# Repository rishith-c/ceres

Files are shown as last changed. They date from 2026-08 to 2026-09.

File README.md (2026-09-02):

# CERES — Field Triage Rover

**A rover that tells you *why* a plant is suffering — thirst, disease, or pests — by
probing the soil, studying the leaves, and fusing both into one honest verdict per plant.**







## Awards

**🏆 2nd Place, Berkeley Robotics Hackathon 2026** (UC Berkeley eHub, August 31) —
won by the only high-school team at a predominantly UC Berkeley student event.

Built by **Rishith Chennupati & Varun Chilukuri**.
Deep technical companion: **[ARCHITECTURE.md](ARCHITECTURE.md)** · agent index: **[llms.txt](llms.txt)**

Every plant monitor gives you numbers. Ceres gives you a diagnosis — and when it isn't
sure, it says **"needs a human"** instead of guessing. Abstention is a feature.

---
 
## How it thinks

```mermaid
graph LR
  A[soil probe<br/>capacitive · 2-pt calibrated] --> C
  B[camera · 4 fenced poses] --> V[VLM leaf classifier<br/>disease vs pest · confidence-gated]
  V --> M[2-of-4 frame vote<br/>abstain by default] --> C[9-rule fusion table<br/>moisture × leaf]
  C --> R[one cause-tagged verdict<br/>fine · dry · sick · needs human]
```

And one full plant stop, as the machines see it:

```mermaid
sequenceDiagram
  participant Pi
  participant Mega
  participant Servo as Probe/Tilt
  Pi->>Mega: PROBE 100
  Mega->>Servo: slewed, pulse-fenced descent
  Note over Mega: FWD refused while probe deployed
  Pi->>Mega: STATUS (settled?) — doubles as watchdog keepalive
  Pi->>Pi: read moisture · dwell · retract
  Pi->>Mega: TILT poses ×4 → capture ×4
  Pi->>Pi: classify ×4 → vote → fuse
  Pi-->>Pi: verdict → live plant board
```

The fusion table is explicit and total — a judge asking "what happens at moisture 0.42
and leaf confidence 0.55?" gets a table lookup, not a vibe. Run `python3 pi/triage.py`
to print it.

## The machine

| Layer | Hardware | Job |
|---|---|---|
| Reflexes | Arduino Mega 2560 | serial protocol, timed motion, 400 ms host watchdog, per-joint safety fences |
| Drivetrain | 2× L298N, 4× TT motors | skid-steer: fwd/rev/spin/arc (12-pin independent wiring) |
| Actuators | PCA9685 → MG90S probe (rack & pinion), MG996R tilt | fenced travel measured on the real hardware |
| Brain | Raspberry Pi 4 (USB-boot) | camera, web GUI + dashboards (systemd), vision pipeline, serial master |
| Heavy vision | laptop over WiFi | YOLOv5n plant tracking (~127 ms/frame), closes a visual-servo loop on the turret |

Web surfaces served by the rover's own Pi (no cloud required):
`:8081` Rover Remote — phone teleoperation, live MJPEG feed, hold-to-drive, one-button
kinematic show · `:8080` live plant board · `:8080/farm` the Farm Board display.

## Safety, by construction

- No untimed motion; every drive command auto-stops; host silence >400 ms cuts motors
- Probe and tilt clamped **at the pulse-write level** to travel limits measured on the
  physical mechanism (the tilt limit was found by successive approximation after it
  hammered its stop — the number is earned, not assumed)
- Driving is refused while the probe is deployed, and vice versa
- 46 automated tests, all passing on the Pi itself: `cd pi && pytest tests`

## Honest ledger

Things that broke and what we did (full narrative in [STATUS.md](STATUS.md)):
- The original L298P motor shield died to reversed battery polarity → dual-L298N architecture
- One MG996R's control board fried (self-drives on bare power) → **retired; the wheels
  became the pan axis** — short spin bursts aim the whole rover
- Rear motors were wired mirror-image → fixed in the firmware direction table
- Campus-network USB noise corrupted serial during streaming → choreography moved on-board
- Not yet done: leaf vision against the live API (needs a key), soil sensor soldering,
  drivetrain on real soil, probe rack limit calibration

## Provenance

This repo's git history **is** the build card: everything before the hackathon's kickoff
commit existed before the event, and everything after was built during it. The probe
module CAD from the original design was lost and is documented as such — nothing here
claims to be more finished than it is.

## Repo map

`firmware/` Mega sketches (rover_motion is the real one; the rest are bench tools) ·
`pi/` the brain: driver, fusion, calibration, vision, GUI, dashboards, 46 tests ·
`mac_tools/` neural leaf tracking · `cad/` surviving chassis CAD + mock assembly ·
`HANDOFF.md` the original design document · `STATUS.md` the living build log

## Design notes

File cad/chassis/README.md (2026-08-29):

# Field Triage Rover — Chassis, Mounts and Turret, v1

Ten parts. Same standard as the probe module: every dimension traced to a
source, boolean-checked, rendered from six angles and inspected before release.

## Chassis geometry

| | |
|---|---|
| Deck | 200 × 140 × 5 mm, top face at Z = 45 mm |
| Wheelbase | 124 mm |
| Track | 170 mm |
| **Overall width with wheels** | **196 mm** |
| Axle height | 32.5 mm (65 mm wheels) |
| Under-deck clearance | 33 mm to the rib bottoms |
| Uno + shield stack top | Z = 87 mm |

**196 mm is the number to check against your row spacing.** You never gave me
pot spacing, so this is sized for a comfortable printed plate, not for your
demo bed. If your pots are closer than ~250 mm on centre, tell me and I'll
narrow the track — it costs one parameter.

The deck top at Z = 45 is not arbitrary: it's set by the 65 mm wheel radius plus
the TT gearbox height, and it's the same Z the probe frame's flange was designed
to bolt to. The two modules line up without adjustment.

## Parts

| File | Qty | Print orientation |
|---|---|---|
| `01_deck` | 1 | flat, ribs up (they print as walls, no support) |
| `02_motor_clamp` | **4** | mouth up |
| `03_motor_gauge` | 1 | flat — **print this first** |
| `04_pi_tray` | 1 | flat |
| `05_uno_tray` | 1 | flat |
| `06_powerbank_sling` | 1 | flat |
| `07_lipo_cradle` | 1 | flat |
| `08_turret_base` | 1 | open face up |
| `09_turret_yoke` | 1 | base down |
| `10_cam_cradle` | 1 | cradle face down |

PETG, 0.2 mm, 4 perimeters, 40% gyroid. Nothing needs support material.

## Three decisions that were made deliberately

**The motor clamp ignores the TT motor's own screw holes.** Vendors disagree on
that pattern and I have not measured yours, so the clamp grips the gearbox body
instead and pulls closed with two M3 bolts into captive hex nuts. It cannot be
wrong about a hole pattern it never uses. Print `03_motor_gauge` first — if the
gearbox does not slide in under light thumb pressure, measure it and tell me
before you print four clamps.

**The LiPo cradle is a strap tray, not a pocket.** You have never given me the
gel-blaster pack's case dimensions, and 3S 2000 mAh bricks range from about
95 × 30 × 20 to 115 × 40 × 28. A toleranced pocket would be a guess dressed up
as precision. The tray takes anything in that range and holds it with two velcro
straps.

**The camera mounts through the C920's 1/4"-20 tripod socket.** That thread is
the one dimensionally guaranteed feature on the camera; the clip's moulded shape
differs between revisions. A raised anti-rotation pad stops the camera pivoting
about the single screw.

**The turret uprights sit outboard at X = ±40.** The C920 is roughly 94 mm wide,
so an inboard yoke would have to be narrower than the camera it carries. Putting
them outboard also lets the tilt servo mount with its long axis horizontal, so
its 53.6 mm tab span fits a 60 mm upright instead of forcing a 66 mm post.

**The pan servo does not carry the camera's overturning moment.** The yoke has a
printed thrust collar that rides in a bore in the turret base. The servo spline
sees torque only. Without this, an MG996R's output bearing takes a bending load
it was never specified for, and the turret develops a wobble by the second hour.

## Assembly order

1. Motor gauge → verify → print four clamps.
2. Clamps to the deck underside, motors in, clamp bolts snug **but not crushed** —
   the gearbox is moulded plastic and will deform.
3. Wheels on. Roll it on the demo surface before adding anything else. If a
   65 mm plastic wheel won't get traction on your soil bed, everything above
   this line is wasted.
4. Power bank sling and LiPo cradle underneath, straps through the deck slots.
5. Pi tray and Uno tray on top. **Nothing may be mounted within 34 mm above the
   Uno tray** — the Inland shield stacks 30 mm and needs finger room above that.
6. Probe frame bolts to the front-edge flange holes; its throat drops through
   the slot in the deck's front edge.
7. Turret base at the rear, yoke on the pan horn, cradle between the uprights.

## Still open

- **Row / pot spacing.** Drives the 196 mm overall width.
- **Motor wiring:** four motors paired onto shield channels A and B, or servos
  moved to a PCA9685 on the Pi so all four channels stay free. This does not
  change any printed part, but it changes what goes on the deck.
- **Wheel choice.** Modelled at the standard 65 × 26 mm TT wheel. A different
  diameter moves the deck height and breaks alignment with the probe frame.

## QC performed

All ten parts watertight, winding-consistent, single-solid, and inside the
Neptune 4 envelope printed flat. Two defects were caught by rendering and fixed:
the turret yoke was two disconnected lumps because the tilt servo pocket cut
clean through the upright, and the original yoke geometry was narrower than the
camera it was supposed to hold.

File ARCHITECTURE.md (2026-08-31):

# Ceres — Architecture & Engineering Notes

The deep-dive companion to the README. Everything here is implemented and testable in
this repo unless explicitly marked as inherited design analysis.

## 1. System topology

```mermaid
graph LR
  subgraph Laptop["Laptop (heavy vision)"]
    T[YOLOv5n tracker<br/>~127 ms/frame CPU]
  end
  subgraph Pi["Raspberry Pi 4 (brain)"]
    G[drive_gui.py :8081<br/>teleop + MJPEG + show]
    D[dashboard.py :8080<br/>plant board + /farm]
    S[station.py<br/>scan → vote → fuse]
    L[leaf.py → Claude VLM]
  end
  subgraph Mega["ATmega2560 (reflexes)"]
    P[serial protocol<br/>115200 8N1]
    W[400 ms watchdog]
    F[pulse-level fences]
  end
  T -- "HTTP /stream, /cmd" --> G
  G -- "USB serial" --> P
  S --> L
  P --> M1[2× L298N → 4× TT motors]
  P --> M2[PCA9685 → probe MG90S ch1, tilt MG996R ch3]
```

## 2. Serial protocol and its timing model

ASCII, newline-terminated, request→`OK|ERR` reply. Commands: `PING FWD REV SPIN ARC
RARC STOP PROBE PAN TILT PANSPIN HOME STATUS`.

The safety-critical property is the interplay of three timers:

| Timer | Value | Consequence |
|---|---|---|
| motion burst | per-command `ms` ≤ 10 000 | no untimed motion exists |
| host watchdog | 400 ms since last RX byte | silent host ⇒ motors cut mid-burst |
| teleop repeat | client streams a 600 ms burst every 300 ms | continuous drive while held |

Result: releasing a button, losing WiFi, or a crashed client all converge to a stop in
≤ 600 ms without any cleanup code running anywhere. The GUI's status poll doubles as the
keepalive during long moves — liveness and telemetry are the same packet.

## 3. Joint fences: measured, then enforced at the lowest level

All servo writes funnel through one function that clamps in pulse space (µs), below the
command layer — so no code path, present or future, can exceed a limit:

- **Tilt 74°–118°.** The floor was found by successive approximation after the mechanism
  hammered its end-stop: lower the bound, listen, repeat. The passing value is the fence.
- **Probe window (pulse-domain, inverted map).** The rack runs mirrored to the original
  design assumption, so `PROBE 0 (retracted) = high pulse`, `PROBE 100 = low pulse`. The
  retracted-detection predicate and the drive interlock were re-derived for the inverted
  map — driving is refused unless the probe is *physically* up, not nominally up.
- **Per-channel slew limits** (µs/s) shape every motion; unused PCA9685 channels are
  actively silenced (zero pulse width) so a floating or failed servo cannot be driven.

## 4. Drivetrain control

Two L298N bridges, all 12 control pins independent, one motor per 2 A channel. Direction
polarity per motor lives in a firmware table (`FWD_HIGH[4]`) — the rear pair is inverted
there because bench testing showed mirror-image wiring; fixing it in the table beats
re-soldering under deadline. Arcs run the inner side at 40 % duty for car-like veers.
PWM is capped at 160/255: 3–6 V motors on an ~9 V post-bridge rail; 160/255 · 9 V ≈ 5.6 V
average at the motor.

After one MG996R's control board failed (it self-drives with no signal — retired), the
pan axis was re-architected onto the drivetrain: short differential spin bursts aim the
whole rover. The tracker compensates with a longer settle cooldown (§6).

## 5. Sensing → judgment

**Moisture** (Adafruit 4026, capacitive, I²C 0x36): raw counts two-point calibrated
(dry air = 0, submerged = 1) with plausibility bounds; a boot self-check makes a broken
probe read as FAULT, never as drought.

**Leaves**: 4 fenced camera poses per plant; each frame classified by a constrained-JSON
VLM call (verdict ∈ {healthy, anomalous, abstain}, cause ∈ {disease, pest}, confidence).
Voting: conviction requires ≥ 2 frames confidently anomalous; acquittal requires ≥ 2
confidently healthy and zero confident convictions; anything else abstains.

**Fusion** is a total function over {LOW, NORMAL, FAULT} × {HEALTHY, ANOMALOUS, UNKNOWN}
— nine explicit rules, thresholds MOISTURE_LOW = 0.35 and confidence floor 0.70. Design
property: no path converts uncertainty into an accusation; every uncertain cell lands on
UNDERWATERED-with-caveat or NEEDS_HUMAN. `python3 pi/triage.py` prints the table.

## 6. Visual servoing (laptop)

YOLOv5n (COCO class 58 "potted plant") through OpenCV DNN, letterboxed 640², ~127 ms/frame
CPU; falls back to HSV green-region segmentation for handheld leaves. Control: deadbands
0.10 (tilt) / 0.18 (pan) of frame; tilt corrects 2° per 320 ms; horizontal correction is a
250 ms spin burst with a 2.2 s cooldown (chassis motion shakes the camera — the loop waits
out its own disturbance). Pan polarity is **self-learning**: after each correction the
tracker checks whether horizontal error shrank; two consecutive regressions flip the
direction mapping at runtime.

## 7. Probe mechanism — inherited design analysis

The original probe drivetrain analysis (design documents; the CAD itself was lost before
this build): module 2, z = 18 pinion, Ø36 mm pitch circle — 0.314 mm of rack travel per
servo degree; MG996R stall derated to the 5.5 V rail gives 56.3 N of linear force against
a 21.9 N moist-soil insertion load (SF 2.57); Lewis tooth stress 7.59 MPa (SF 2.37 in
PETG); guided-blade buckling SF > 100. The current build substitutes an MG90S (~12 N at
stall through the same pinion) at the builder's direction — sufficient only for loose
potting mix, and recorded as such rather than re-rated.

## 8. Power tree

```
3S LiPo (11.1 V, 30C) ─┬─► L298N #1 ─► L298N #2      (motor rail, daisy-chained)
                       └─► buck → 6.0 V ─► PCA9685 V+ (servo rail, own return path)
power bank ─► Pi (USB-C) ─► Mega (USB data+power)
single common ground; servo current returns via the PCA9685 terminal block,
never through the Mega/USB ground (learned the hard way — see failure ledger)
```

## 9. Failure ledger with root causes

| Failure | Root cause | Response |
|---|---|---|
| L298P shield dead | reversed battery polarity at BAT terminals | dual-L298N architecture; polarity ritual |
| Serial corruption / USB dropouts | servo return current through USB ground + cable | ground re-route; on-board choreography; link-quality PING metric (n/60) |
| Wheels fought on every command | rear motors wired mirror-image | firmware polarity table |
| Tilt hammering | commanded past unmeasured mechanical floor | successive-approximation calibration → fence |
| Servo self-drives unpowered inputs | fried control board (confirmed: spins with zero pulses) | retired; wheels became pan axis |
| Twitch at power-on | MCU boot window leaves EN pins floating | battery-last power order; pull-down fix documented |

## 10. Verification

46 tests, all runnable on the target Pi (`cd pi && pytest tests`): protocol framing and
error taxonomy, watchdog-keepalive behavior, every fusion cell and both thresholds at
their boundaries, calibration bounds and fault paths, vision abstention on seven failure
modes, scan-pose fencing and vote outcomes. Firmware compiles warning-clean for
`arduino:avr:mega`; every flash in the log was verified by avrdude readback.

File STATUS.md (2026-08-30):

# Project status — the rover is named CERES

## 2026-08-30 late — PI↔MEGA INTEGRATION LIVE
Mega on the Pi's USB (/dev/ttyACM0). Rover Remote GUI (pi/drive_gui.py)
runs as systemd service on :8081 — live MJPEG camera feed, hold-to-drive
pad (600 ms bursts, watchdog-safe), tilt/pan/probe controls, live status.
First Pi-commanded motion executed via the full chain (browser→Pi→serial→
firmware). Dashboard on :8080. Both survive reboot.

## 2026-08-30 evening — Pi COMMISSIONED
Pi 4 ("varun", user varun, 10.59.112.136 on campus net + RPi Connect as
backup) boots from 128 GB USB (102 GB free), reachable by key-auth SSH
from the Mac. Code deployed to ~/rover with venv (.venv, system-site,
cv2 4.10 via apt + anthropic/pyserial/pytest via pip). **All 45 tests
pass ON THE PI.** Remaining to first real leaf judgment: export
ANTHROPIC_API_KEY on the Pi, plug Mega + C920 into Pi USB.

## 2026-08-30 — vision + scan pipeline ready for the Pi
`pi/` now carries the whole per-plant inspection chain, hardware-free
tested (45 tests): `camera.py` (C920 capture, warmup burst),
`leaf.py` (Claude vision; verdict + **cause: disease vs pest** + abstain),
`station.py` (`scan_plant()`: 4 fenced poses, staggered pan nudges,
majority-with-abstention across frames, fused into a flag; moisture=None
honestly abstains until the soil sensor is wired). Pi setup needs:
`pip install pyserial anthropic opencv-python` + `ANTHROPIC_API_KEY`.
Pi boots from USB (SD dead); SSH was not enabled in the image — fix by
dropping `ssh` + `userconf.txt` on the boot partition. No plant-training
data exists on the WC18 drive (industrial video only) — the VLM route is
deliberate, per HANDOFF known-problems.

## MILESTONE 2026-08-29 late: full bench bring-up complete
Every actuator verified moving under serial command on the Mega:
wheels (timed + watchdog), probe (gentle, fenced), tilt (positional),
pan (PANSPIN timed nudges — the servo is a continuous type). Link clean.
Tilt mechanism calibrated 2026-08-30: hammers its stop below ~74 deg;
firmware now fences TILT to 74-118 (like the probe's 30-150 fence).
firmware/turret_duet is a standalone USB-free pan/tilt show (74-118 wave,
staggered pan nudges — simultaneous big-servo peaks caused intermittent
hammering; USB streaming reliably kills the link until the ground/cable
fix happens). Still open before the hackathon: probe rack limit calibration, drivetrain
on real ground, deck reprint (axis defect), probe CAD recovery/rebuild,
a real positional pan servo, 5 A servo buck + inline fuse for demo day.

# Project status — 2026-08-28 session

## What happened to the files

Only the chassis half of the project survived on this machine, in
`~/Developer/files/` (copied here under `cad/`; the originals were left in
place — treat this repo as canonical from now on and delete `~/Developer/files`
when convenient). Searched the whole disk, Downloads archives, and git
history: **these HANDOFF §6 files are lost**, not misplaced:

- `firmware/rover_motion.ino` (original) — **rebuilt this session**, see below
- `cad/probe_module.py` + probe STEP/STL/renders — **still missing**
- `cad/design_calcs.py` / `design_calcs.txt` — **still missing**
- QC harnesses `build_and_inspect.py`, `build_chassis.py` — **still missing**

The probe module was NOT recreated on purpose: HANDOFF §5 records its locked
design values but not the full part geometry, and §9 forbids replacing
verified numbers with plausible ones. If the original session's outputs exist
anywhere (another machine, a download link, chat history), recover them.
Otherwise the probe CAD must be re-derived properly — through the
aero-mechatronics/cad pipeline, reproducing the §5 numbers exactly — before
printing probe parts. The chassis is fine: its source (`cad/chassis_module.py`)
survived.

## Rebuilt this session

**`firmware/rover_motion/rover_motion.ino`** — rewritten from the HANDOFF §4
spec. Compiles clean for `arduino:avr:uno` (7836 B flash / 492 B RAM). All
specified behaviours implemented: timed motion with auto-stop, 400 ms host
watchdog, PROBE refused while moving, ~83 °/s servo slew, READY banner,
STATUS fields, DIR=digitalWrite / PWM=analogWrite / stop=analogWrite(0).
Deltas from the (unseen) original — flagged, not silent:

- Wiring assumption: **§3 resolution 1** (wheels paired on channels A/B,
  servos on D11/D12/D2). If you pick the PCA9685 route instead, PROBE/PAN/
  TILT/HOME move to the Pi and the firmware shrinks to wheels-only.
- Added the reciprocal safety guard: drive commands are refused while the
  probe is deployed (`ERR probe_deployed`).
- PWM capped at 200/255 in firmware (paired motors ~2.4 A stall vs the 2 A
  L298 channel).
- Baud 115200. Drive durations capped at 10 s.
- The watchdog means the Pi **must keep talking during motion** — the driver's
  `wait_for_stop()` polls STATUS and is that keepalive. Not flashed to
  hardware yet; bench-test PWM polarity (A_FORWARD/B_FORWARD constants) first.

## New this session (HANDOFF §8 tasks 1–4) — 37 tests pass, no hardware needed

- `pi/rover.py` — serial driver: READY sync on connect (reset-on-open),
  OK/ERR/timeout parsing, STATUS dataclass, wait_for_stop/wait_for_settled,
  client-side validation. No sequencing logic, per the task spec.
- `pi/triage.py` — the never-cut fusion layer. Total 3×3 rule table
  (moisture LOW/NORMAL/FAULT × leaf HEALTHY/ANOMALOUS/UNKNOWN), abstention
  first-class. Thresholds: moisture LOW < 0.35, leaf confident ≥ 0.70.
  `python3 pi/triage.py` prints the judge-ready table. The §8 judge case
  (moisture 0.42, confidence 0.55 → NORMAL × UNKNOWN → needs_human) is a
  tested lookup.
- `pi/soil.py` — two-point calibration (raw 200–2000 counts → 0–1) with
  plausibility bounds and a boot self-check, so a broken probe reads as a
  FAULT (→ triage abstains), never as a drought.
- `pi/leaf.py` — hosted-VLM leaf call (Claude, `claude-opus-5`, constrained
  JSON schema). Every failure — no key, no network, refusal, garbage output,
  leaf not visible — returns abstain. Needs `ANTHROPIC_API_KEY` and
  `pip install anthropic` on the Pi. Untested against the live API; the
  parsing/abstention paths are unit-tested with a fake client.
- Run everything: `pytest pi/tests` (needs pytest; pyserial only on the Pi).

## Defect found 2026-08-28 while building the mock assembly (cad/mock_assembly.py)

**The deck's feature axes conflict with the designed track.** The deck is
200 × 140 with the probe notch centered on a 200 mm edge and the turret on the
opposite 200 mm edge — i.e. the features treat the 140 axis as fore-aft. But
the motor clamps at (±56, ±62) put the wheels at X ≈ ±85 (track 170 as
designed), and a Ø65 wheel (top at Z = 65) at X 72–98 passes straight through
the deck plate corners (deck sits at Z ≈ 40–50, spanning X ±100). Track 170 /
overall width 196 is only possible if the deck is ~140 wide at the wheel
stations — the 200 axis must run fore-aft, which contradicts the probe/turret
edge placement. Corroborating signs of the same axis mix-up in `make_deck()`:
half of each motor-clamp bolt pair lands at y = ±74, off the ±70 plate edge;
and `TRACK` is derived from `DECK_W` while the clamp X positions also use
`DECK_W`. Separate 4–5 mm issue: gearbox top sits at Z = 44, so the deck
bottom must be at 45 (per the code's own `DECK_Z` formula) — the README's
"top face at Z = 45" would put the deck bottom at 40, inside the gearboxes.

**Do not print `01_deck` until this is resolved.** Fix in chassis_module.py:
keep the 200 axis fore-aft, move the probe slot/flange to one 140 edge and
the turret pattern to the other, put the wheelbase (±62) along the long axis,
then re-run QC and re-render. The mock viewer shows the clip honestly —
explode it and look at the wheel corners.

## 2026-08-29 — shield died, architecture pivoted

The Inland L298P shield took the 3S pack reverse-polarity (BAT + to −) and
its motor stage is dead: logic LED lives, no channel moves. Uno, motors,
and pack survived. New electrical architecture, replacing HANDOFF §3's
open decision with a hybrid of both options:

- **Wheels:** TWO L298N modules, one per side, all 12 control pins wired
  independently (per the LastMinuteEngineers diagram, at the builder's
  request), now on an **Arduino Mega 2560** (pin map also works on an Uno).
  Board 1 = LEFT: ENA 9, IN1 8, IN2 7, IN3 5, IN4 4, ENB 3 (verified working
  with the LME demo). Board 2 = RIGHT: ENA 10, IN1 11, IN2 12, IN3 13,
  IN4 2, ENB 6.
  Battery daisy-chain: pack + → board1 +12V → jumper → board2 +12V; pack −
  → board1 GND → jumper → board2 GND; one wire board1 GND → Uno GND.
  Per-motor direction flips live in FWD_HIGH[] in the firmware.
- **Servos:** PCA9685 on the **Mega's** I²C (SDA 20, SCL 21) — moved off
  the Pi 2026-08-29 evening so one MCU owns all deadlines and bench testing
  needs no Pi. Roster AS PLUGGED (re-confirmed after two map flip-flops):
  ch0 tilt = MG996R (healthy), **ch1 probe = MG90S** (fenced 900–2400 µs,
  retract = 30°; against the force calc — loose mix only), ch2 pan =
  **DISABLED**: that servo spins continuously on any pulse incl. center
  (continuous-rotation clone or broken). Positional PAN stays disabled, but
  **PANSPIN <ms> <L|R>** (1250/1750 µs, max 2 s, then pulses cut) gives
  working timed nudges — verified moving both directions on the bench. Probe slew ~50°/s,
  pan/tilt ~83°/s. Probe rack travel limits NOT yet calibrated — limit
  finder exists (firmware/probe_limit_finder) but the session stalled;
  carriage reported to crash at fence ends, so the real travel is
  narrower than 30–150°.
- **Firmware v3** (`rover_motion.ino`, Mega + Adafruit PWM Servo Driver
  lib): full HANDOFF §4 protocol restored — wheels AND PROBE/PAN/TILT/HOME,
  7-field STATUS, both interlocks back in firmware (PROBE refused while
  moving, drive refused while probe deployed), ~83°/s slew via PCA9685,
  MAX_PWM 160. `pi/rover.py` matches (probe/pan/tilt/home/sample());
  `pi/actuators.py` + `servo_test.py` retired (git history has them).
- Bench sketches: `firmware/motor_test/` (old shield, 4-channel),
  `firmware/motor_test_l298n/` (interactive), `firmware/motor_demo_4x/`
  (auto-looping LME-style), `pi/servo_test.py` (PCA9685). All compile for
  Mega and Uno.

## Still open (HANDOFF §7 — answers needed, don't guess)

Pot spacing, wheel diameter, TT gearbox gauge, MG996R gauge, and the
A/B-pairing vs PCA9685 wiring decision. Plus §8 task 5 (row sequencing) —
blocked on the stop-at-plant sensing decision.

**LiPo answered 2026-08-29** (Amazon listing, Tosiicop 2-pack): 3S 11.1 V
2000 mAh **30C** (not 10C as HANDOFF §2 said — 60 A short-circuit capable,
the inline fuse is not optional), 106 × 18 × 20 mm, 73 g, SM-2P discharge
plug + XH-4P balance, mini-Tamiya adapter included. Fits the strap-tray
cradle easily. All four TT motors are currently wired to shield channels
A–D for bench testing with firmware/motor_test/motor_test.ino.

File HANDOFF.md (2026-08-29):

# Field Triage Rover — Project Handoff

You are picking up an in-progress hardware project. This document is the single
source of truth. Everything below has been verified against a real source —
datasheets, official CAD files, or vendor spec pages. **Do not silently replace
any number here with a guess.** If a dimension is missing, it is missing on
purpose and is listed under "Open questions" — ask, don't invent.

---

## 1. What this is

A small autonomous rover for the **Berkeley Robotics Hackathon** (two people,
one build day: Rishith Chennupati and Varun Chilukuri).

It drives along a row of potted plants and stops at each one. At every stop it
drives a soil probe into the pot, reads soil moisture and temperature, retracts,
then aims a webcam at the canopy and captures a leaf image. Both signals are
fused **per plant** into one cause-tagged flag — *underwatered* vs *diseased* vs
*fine* — instead of reporting raw numbers a human has to interpret.

**The triage/fusion layer is the differentiator and the last thing to cut.**
A rover that reports four numbers has been built many times; one that says
"plant 14: moisture normal, leaf spotted → likely disease, not water" has not.

Cut order if the schedule slips, worst first:
1. Presentation dashboard — cut first
2. Turret / leaf vision
3. Probe subsystem
4. **Per-plant fusion — never cut**

Judging panel includes people from frontier robotics labs. **Claim only what is
actually built.** A smaller fully-real system beats a larger partly-narrated one.

---

## 2. Hardware inventory — all verified

| Component | Verified dimensions / spec | Source |
|---|---|---|
| Raspberry Pi 4B | 85.0 × 56.0 mm, M2.5 holes on a 58 × 49 rectangle, 3.5 mm inset | RPi mechanical drawing |
| Arduino Uno R3 | 68.6 × 53.4 mm, standard Arduino 4-hole pattern | Arduino |
| Inland L298P 4-ch motor shield | 65 × 50 × 30 mm stacked, 3× M3 fixing holes, PH2.0-2P motor connectors, onboard slide switch, BAT input 7–12 V, <4 A total | Micro Center KB article 678 |
| Adafruit 4026 STEMMA soil sensor | 76.20 × 13.97 × 6.37 mm, 1.57 mm FR4, components occupy 0–19.53 mm from the connector end, **56.67 mm of bare blade** | measured from Adafruit's own STEP file |
| MG996R servo ×3 | 40.7 × 19.7 × 42.9 mm, tab span 53.6, hole pitch 49.5, stall 9.4 kgf·cm @4.8 V / 11.0 @6.0 V, stall current 2.5 A | TowerPro, cross-checked Waveshare + Handson |
| Yellow TT gearmotor ×4 | 70 × 37 × 22.5 mm, dual shaft, 1:48 | vendor spec — **hole pattern NOT verified** |
| TT wheel ×4 | assumed 65 mm dia × 26 mm — **not confirmed** | assumption |
| Logitech C920 webcam | mounts via its 1/4"-20 UNC tripod socket | Logitech |
| Energizer power bank | 148.59 × 68.33 × 17.53 mm, 10,000 mAh, 22.5 W | Micro Center listing |
| 3S LiPo (gel-blaster pack) | 11.1 V 2000 mAh 10C, SM-2P plug — **case dimensions NOT measured** | user |
| Printer | Elegoo Neptune 4, 225 × 225 × 265 mm, 0.4 mm nozzle | — |

### Corrections to bad vendor data — do not regress these

- Micro Center lists the 4026 as **"Temperature, Humidity"** with **"Range 100mm
  to 2000mm."** Both wrong. It is a capacitive soil-moisture sensor; 200–2000 is
  the **raw capacitance count** (dry→wet), not millimetres. Temperature is the
  ATSAMD10's internal die sensor, ±2 °C.
- **There is no humidity sensor in this build.** The project write-up says
  "moisture, temperature, humidity." Only the first two exist. Either add an
  SHT31/DHT22 or drop the humidity claim from the pitch.
- The Inland KB article's example sketch has broken `pinMode` calls (it sets
  `MAPin` four times and never `MBPin`/`MCPin`/`MDPin`). Don't use it as a reference.

---

## 3. Electrical architecture

### Motor shield pinout (verified)

| Channel | Direction pin | PWM pin | AVR timer |
|---|---|---|---|
| A | D3 | D6 | Timer0 |
| B | D4 | D5 | Timer0 |
| C | D7 | D10 | **Timer1** |
| D | D8 | D9 | **Timer1** |

### HARD CONSTRAINT — read this before touching motor code

On an Uno R3 the **Servo library owns Timer1**, which is the timer that generates
PWM on **D9 and D10**. The moment any servo is attached, channels C and D lose
speed control and become on/off only.

There are four TT motors and three servos. They cannot coexist on this shield.

Two acceptable resolutions:
1. **Pair the wheels.** Left two motors into channel A, right two into channel B.
   Skid-steer 4WD cannot use independent per-wheel speed anyway. C and D stay
   empty and the conflict disappears. Cost: ~2.4 A stall through a 2 A channel,
   so cap PWM and never let them stall.
2. **Move all three servos to a PCA9685** on the Pi's I²C bus (~$8). Arduino does
   wheels only; the Pi drives the turret and probe. Cleanest split, and it puts
   the camera and the turret on the same machine. Cost: one extra part.

**This decision is still open.** It does not change any printed part.

### Board choice: Uno R3, not R4

R3 was chosen deliberately. The Servo/Timer1 interaction on AVR is documented
with a known workaround; the equivalent behaviour on the R4's Renesas timers is
not. The R4 also has a core bug where `digitalWrite()` on a pin that previously
saw `analogWrite()` does not restore a clean rail. The firmware respects that
anyway: **DIR pins are only ever `digitalWrite`, PWM pins only ever `analogWrite`,
and motor stop is `analogWrite(pin, 0)`.** Keep it that way.

### Free pins after the shield

Shield occupies D3–D10. Free: **D2, D11, D12, D13, A0–A5.**
Servos go on **D11, D12, D2**. Avoid D13 (onboard LED + resistor) and D0/D1
(hardware UART — also where the shield's HM-10 header sits, and the same UART
the Pi's USB connection uses; leave that header unpopulated).

### Power rails

The pack is a 3S LiPo at 10C — 20 A available. Steady-state draw is ~1.1–1.3 A,
worst case ~3.5 A. Capacity is not the constraint; rail separation is.

| Rail | Feeds | Notes |
|---|---|---|
| 8.5 V buck | Shield **BAT** terminal | Shield spec is 7–12 V; 8.5 V puts ~6 V on the motors after the L298 bridge drop. Raw 11.1 V would put ~8.6 V on 3–6 V motors. |
| 5.5 V buck, **5 A minimum** | 3× servo V+ only | MG996R stalls at 2.5 A each. A 3 A buck is undersized. |
| 5.1 V buck | Raspberry Pi | Pi then powers the Uno over USB. |

Non-negotiables: inline fuse on the pack positive, 3S low-voltage alarm on the
balance lead, common ground star point, 1000 µF at the servo rail and 470 µF at
the shield BAT input. The shield's onboard slide switch **is** the master switch —
don't add a second one. The Uno auto-selects VIN over USB, so having the Pi
plugged in at the same time is safe.

**Never power servos from the Arduino 5 V pin or the shield's regulator.**
That regulator is good for maybe 500 mA against a ~2 A servo peak. This is the
single most common way this exact build dies.

---

## 4. Firmware — already written

`rover_motion.ino` is complete and compiles for the Uno R3. It is a serial slave;
the Pi owns sequencing, vision and triage, the Arduino owns anything with a
deadline.

### Protocol (ASCII, newline-terminated)

```
PING                   -> OK PONG
FWD <ms> <pwm>         -> OK FWD      drive forward, auto-stops after <ms>
REV <ms> <pwm>         -> OK REV
SPIN <ms> <pwm> <L|R>  -> OK SPIN
STOP                   -> OK STOP
PROBE <0-100>          -> OK PROBE    0 = retracted, 100 = fully inserted
PAN <deg> / TILT <deg> -> OK PAN|TILT
HOME                   -> OK HOME
STATUS                 -> OK <drive> <pwm> <probe> <pan> <tilt> <settled> <uptime>
error                  -> ERR <reason>
```

Safety behaviours already implemented, keep them:
- **No untimed motion.** Every drive command carries its own duration.
- **Host watchdog.** If the Pi goes silent while wheels turn, motors cut.
- **`PROBE` is refused while the chassis is moving.** A probe part-way down while
  the rover rolls is a snapped probe.
- **Servos slew at ~83 °/s** rather than snapping.
- A `READY` banner is emitted after init because opening the serial port resets
  the MCU — the Pi should sync on that instead of guessing.

Firmware rules that must hold in any Pi-side driver you write:
- **Never park the probe loaded.** Insert, dwell, retract. Full stall torque is
  fine for a 1–2 s insertion; holding position against soil will cook the servo.
- **Dwell before reading temperature** — the die sensor needs seconds to settle.
- **Two-point calibrate moisture** (dry in air, submerged in water) so the number
  is defensible when a judge asks what the units are.

---

## 5. CAD — already designed and verified

All parametric CadQuery. Two source modules regenerate everything:

- `probe_module.py` — soil probe actuator (5 parts)
- `chassis_module.py` — chassis, mounts, turret (10 parts)
- `design_calcs.py` — every number the probe geometry derives from

### Probe actuator — locked design values

| Quantity | Value | Reasoning |
|---|---|---|
| Insertion depth | 35.0 mm | capped by 56.67 mm bare blade − 20 mm dry margin |
| Throat ground clearance | 12.0 mm | blade tip parks here |
| Stroke | 47.0 mm | clearance + depth |
| Gearing | module 2, z=18 pinion, Ø36 pitch, 12 mm face | smallest set clearing 47 mm at a conservative 150° servo sweep |
| Backlash | 0.30 mm, taken from rack tooth thickness | |
| Linear force at stall | 56.3 N | MG996R derated to the 5.5 V rail |
| Design load | 21.9 N | moist garden soil: tip bearing + skin friction |
| Safety factor | 2.57 (6.43 in loose potting mix) | |
| Gear tooth stress | 7.59 MPa (Lewis) | SF 2.37 in PETG |
| Blade buckling | SF > 100 guided, 3.2 unguided | why the throat exists |
| Dry margin at full insertion | 21.7 mm | |

**Graceful degradation:** the design assumes 150° of servo sweep, which needs a
600–2400 µs pulse range rather than the default 1000–2000 µs. At a worst-case
120° the insertion depth drops to 25.7 mm — shallower but still a valid reading.

**Out of scope:** packed clay needs 52.6 N, above what's reliably available.
Use loose potting mix in the demo pots. That's a variable you control.

### Chassis geometry

| | |
|---|---|
| Deck | 200 × 140 × 5 mm, top face at **Z = 45 mm** |
| Wheelbase | 124 mm |
| Track | 170 mm |
| Overall width with wheels | **196 mm** |
| Axle height | 32.5 mm (65 mm wheels) |
| Uno + shield stack top | Z = 87 mm |

Z = 45 is not arbitrary — it's the 65 mm wheel radius plus the TT gearbox height,
and it's the same Z the probe frame's mounting flange targets. The two modules
bolt together with no adjustment. **If the wheel diameter changes, both modules
must be regenerated.**

### Part list

**Probe module** — `01_frame`, `02_carriage`, `03_pinion`, `04_clamp`, `05_servo_gauge`
**Chassis** — `01_deck`, `02_motor_clamp` (×4), `03_motor_gauge`, `04_pi_tray`,
`05_uno_tray`, `06_powerbank_sling`, `07_lipo_cradle`, `08_turret_base`,
`09_turret_yoke`, `10_cam_cradle`

All 15 parts: watertight, winding-consistent, single-solid, and fit the Neptune 4
envelope printed flat. Boolean interference checks are clear between frame and
carriage at both stroke ends, and between frame and pinion.

### Print settings

PETG, 0.2 mm layers, 4 perimeters, 40% gyroid. No supports on any part.
PLA works but cracks instead of yielding when the probe hits a stone.

**Two orientations are load-bearing, not preferences:**
- `02_carriage` and `03_pinion` must print **flat**, teeth in the layer plane.
  Printed upright the teeth load across layer lines and the Lewis stress
  calculation above is void.
- `01_frame` prints with its −Y face on the bed so all channel walls come out
  vertical and the throat mouth (a loft, not a chamfer) needs no support.

### Design decisions made deliberately — don't "improve" these

- **No printed servo spline anywhere.** A printed 25T spline strips on the first
  stall. The metal horn carries torque; printed parts have a 24 mm horn pocket
  with four radial slots that accept any horn hole between r=5 and r=11, so
  nothing needs drilling.
- **The motor clamp ignores the TT motor's own screw holes.** Vendors disagree
  on that pattern and it hasn't been measured. The clamp grips the gearbox body
  and pulls closed on captive M3 nuts. It can't be wrong about a pattern it
  never uses.
- **The LiPo cradle is a strap tray, not a pocket.** 3S bricks range from about
  95×30×20 to 115×40×28 and this one hasn't been measured.
- **The camera mounts through the C920's 1/4"-20 socket**, with a raised
  anti-rotation pad. That thread is the only dimensionally guaranteed feature;
  the clip's moulded shape varies between revisions.
- **The pan servo carries no overturning moment.** The yoke rides on a printed
  thrust collar in the turret base bore, so the MG996R spline sees torque only.
  Without it the turret develops a wobble within an hour.
- **Turret uprights sit outboard at X = ±40** because the C920 is ~94 mm wide.
- **Two gauge coupons exist for a reason.** `05_servo_gauge` (8 min) and
  `03_motor_gauge` (5 min) verify the two component fits that are based on
  disputed vendor data. Print both before committing to the full parts.

---

## 6. Expected files on disk

```
field-triage-rover/
├── firmware/
│   └── rover_motion.ino
├── cad/
│   ├── design_calcs.py          # regenerates every probe number
│   ├── design_calcs.txt         # last run output
│   ├── probe_module.py
│   ├── chassis_module.py
│   ├── probe_module/{step,stl,render}/
│   └── chassis/{step,stl,render}/
└── HANDOFF.md                   # this file
```

Rebuild everything with CadQuery 2.8 (`pip install cadquery --break-system-packages`).
QC harnesses `build_and_inspect.py` and `build_chassis.py` re-export, re-run the
interference and envelope checks, and re-render six views per part.

---

## 7. Open questions — ask, do not guess

1. **Row / pot spacing.** Drives the 196 mm overall width. If pots are closer
   than ~250 mm on centre, the track has to narrow.
2. **Wheel diameter.** Modelled at 65 mm. Any change moves the deck height and
   breaks probe/chassis alignment.
3. **TT gearbox cross-section.** Print `03_motor_gauge` and confirm before
   printing four clamps.
4. **MG996R tab pattern.** Print `05_servo_gauge` and confirm.
5. **3S LiPo case dimensions.**
6. **Motor wiring:** wheels paired on channels A/B, or servos moved to a PCA9685?

---

## 8. Suggested next tasks, in order

1. **Pi-side Python driver** for the serial protocol in §4 — a `Rover` class with
   connection handling (tolerate the reset-on-open), command/ack parsing, and
   timeouts. No sequencing logic yet.
2. **Fusion rule table.** Four cells: {low, normal moisture} × {leaf healthy,
   anomalous}, each mapping to a flag, plus abstention as a fifth outcome. This
   is testable with no hardware, so it can be built in parallel with mechanical
   debugging. It's also the thing a judge will ask about — "what happens at
   moisture 0.42 and leaf confidence 0.55" needs a table, not an inference.
3. **Moisture calibration routine** — two-point normalisation, plus a boot-time
   self-check so a broken probe reads as a fault rather than as a drought.
4. **Leaf vision call** with confidence-aware abstention ("needs human
   inspection") instead of a forced guess.
5. **Row sequencing** — see the open risk below.

### Known unsolved problems, honestly stated

- **Stopping at the right plant is open-loop.** `FWD 800 120` covers a different
  distance on a table than on soil, and TT motors are badly mismatched
  pair-to-pair. Over six plants the error compounds until the probe hits dirt
  between pots. Cheapest fix: don't measure distance at all — put a reflectance
  sensor or limit switch at each pot and drive until it fires.
- **The leaf model doesn't exist yet.** PlantVillage-trained classifiers report
  ~99% on that dataset and fall apart on real leaves under real lighting.
  Either use a hosted VLM with a constrained prompt, or restrict the claim to
  something classical CV can actually support.
- **The turret has no idea whether the leaf is in frame.** It pans to a fixed
  angle and captures whatever is there.
- **Traction on soil is untested.** TT motors, plastic wheels, a LiPo, a Pi and
  a probe rack is a heavy low-torque platform. Test the drivetrain on the actual
  demo surface before building anything on top of it.

---

## 9. How to work on this

- Don't replace a verified dimension with a plausible-looking one. Every number
  in §2 has a source; if you need one that isn't there, ask.
- Regenerate CAD from the parametric modules — don't hand-edit STLs.
- After any geometry change, re-run the QC harness and **look at the renders**.
  Five real defects in this project were caught by rendering and inspecting from
  six angles, not by the numbers: a throat that trapped the carriage at full
  insertion, a gusset built on the wrong workplane, a pinion placement that drove
  the gear through a side wall, a turret yoke that came out as two disconnected
  lumps, and a yoke narrower than the camera it was meant to hold.
- Prefer a smaller working system over a larger described one. See §1.

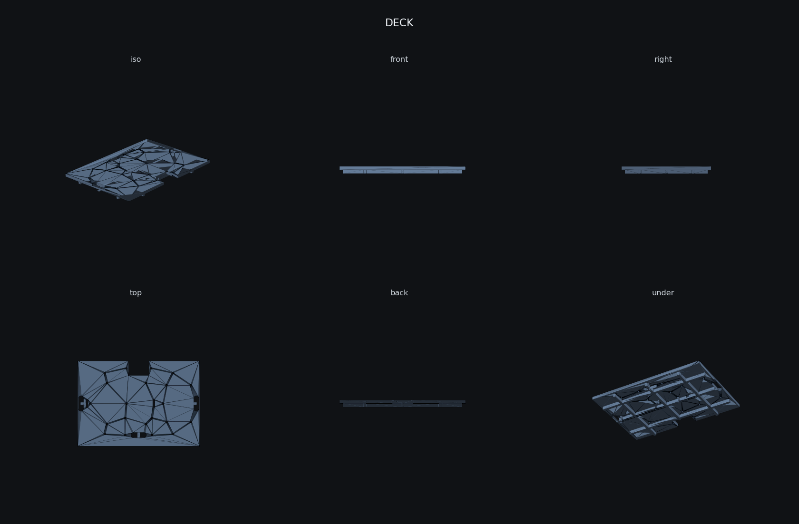
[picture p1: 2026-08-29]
cad/chassis/render/01_deck.png

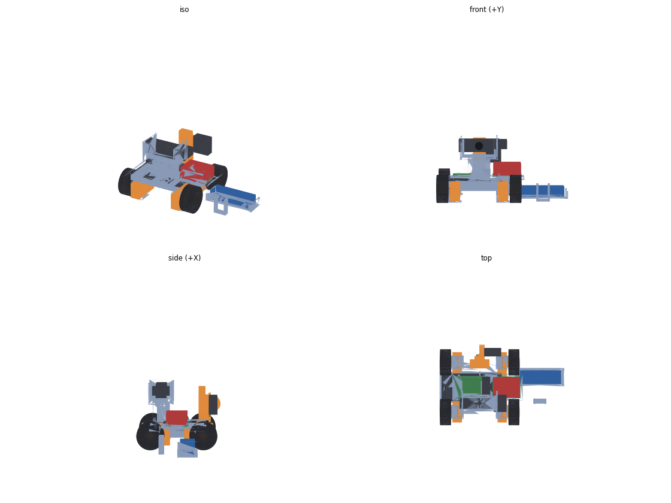
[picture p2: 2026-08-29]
cad/render/mock_qc.png

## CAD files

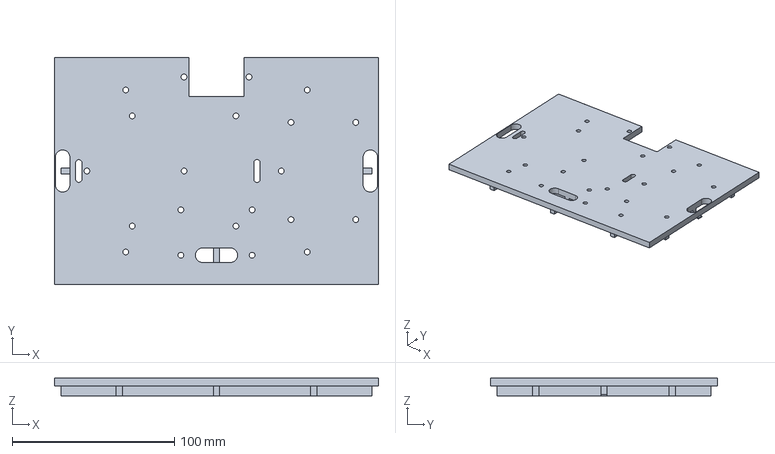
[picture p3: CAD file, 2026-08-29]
cad/chassis/step/01_deck.step
200.0 x 140.0 x 11.0 mm

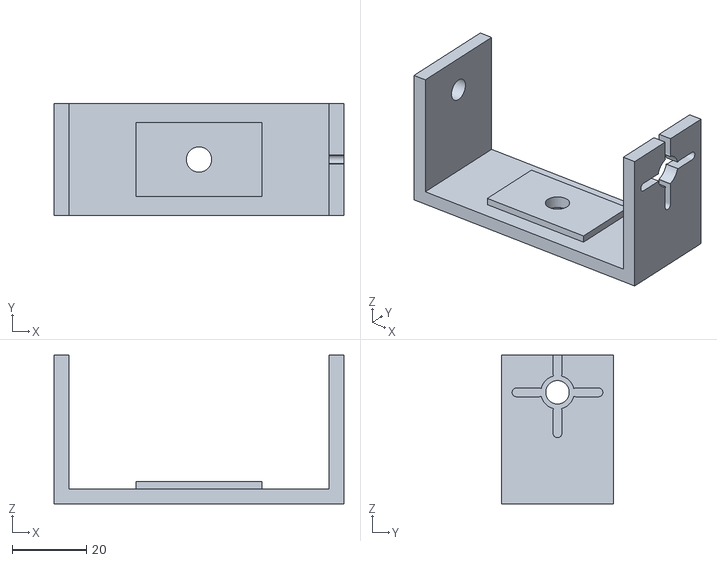
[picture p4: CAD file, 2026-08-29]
cad/chassis/stl/10_cam_cradle.stl
78.0 x 30.0 x 40.0

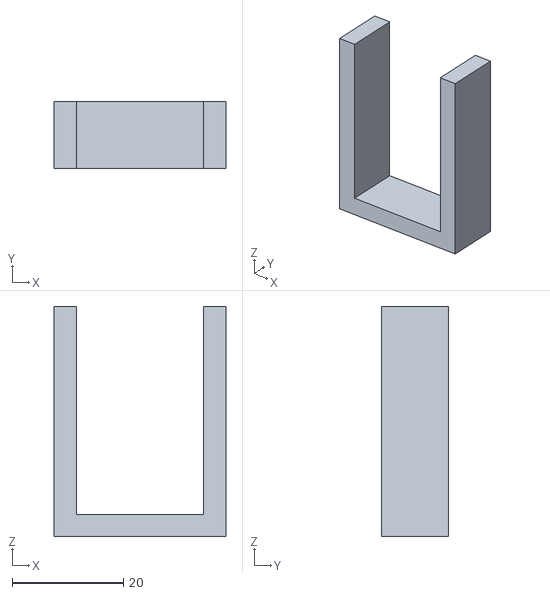
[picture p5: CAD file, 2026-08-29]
cad/chassis/stl/03_motor_gauge.stl
30.9 x 12.0 x 41.3

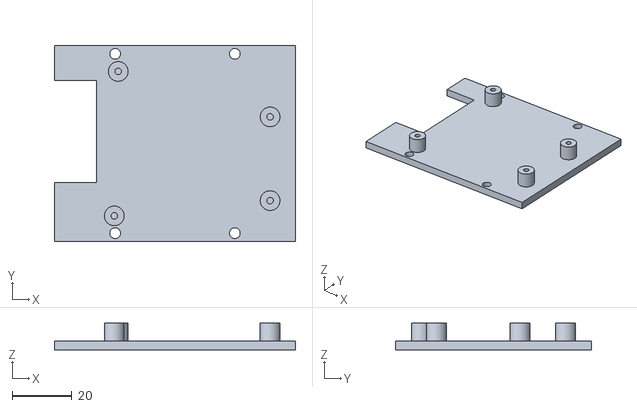
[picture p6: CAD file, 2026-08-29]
cad/chassis/stl/05_uno_tray.stl
80.6 x 65.4 x 9.00

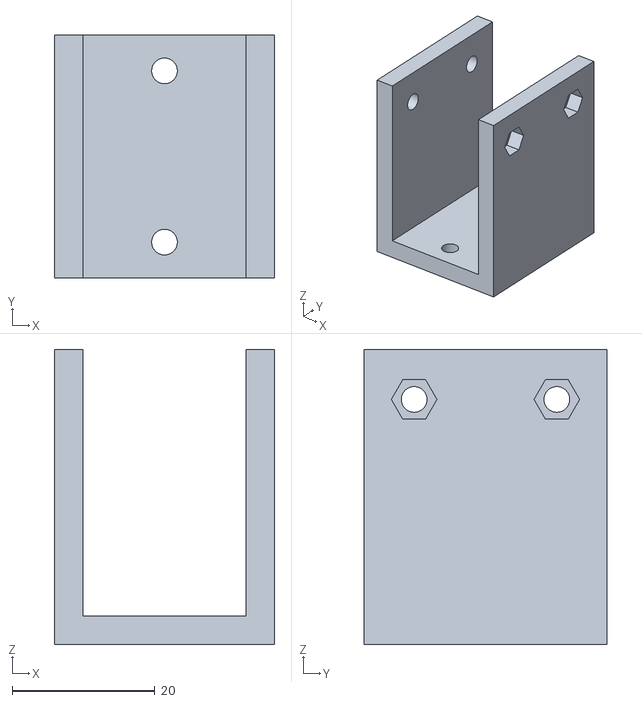
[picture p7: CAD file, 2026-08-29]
cad/chassis/stl/02_motor_clamp.stl
30.9 x 34.0 x 41.3

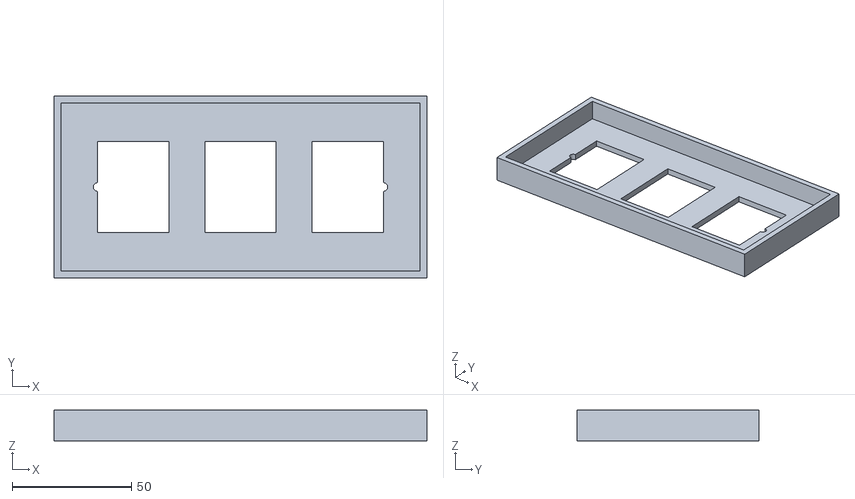
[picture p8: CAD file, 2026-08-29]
cad/chassis/stl/06_powerbank_sling.stl
156.6 x 76.3 x 13.0

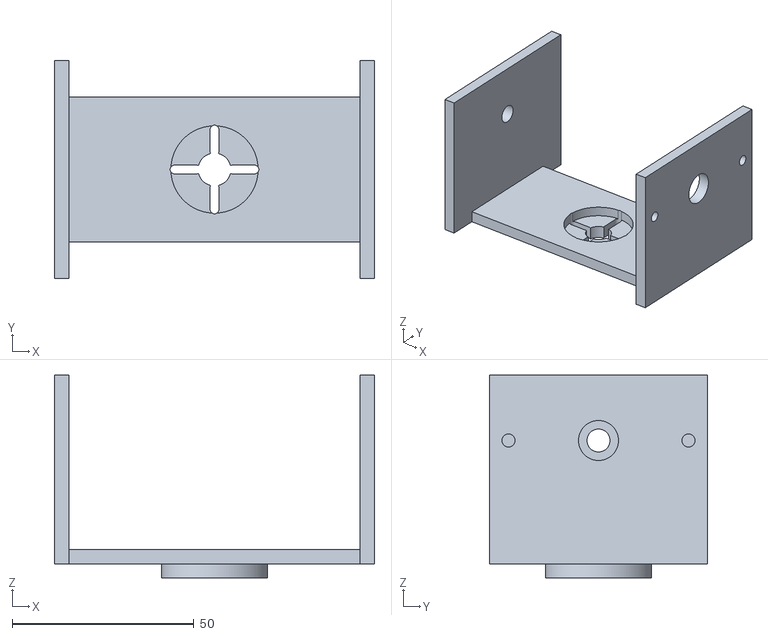
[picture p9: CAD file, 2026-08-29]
cad/chassis/stl/09_turret_yoke.stl
88.0 x 60.0 x 55.8

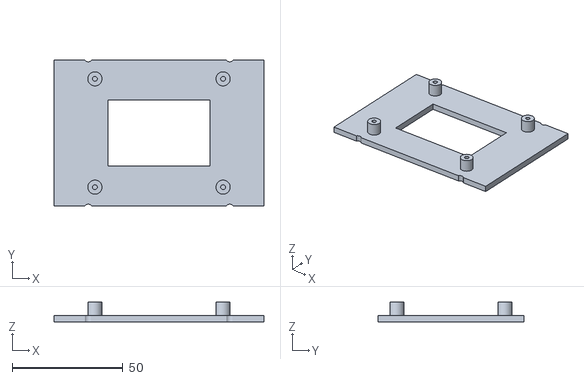
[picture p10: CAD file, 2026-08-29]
cad/chassis/stl/04_pi_tray.stl
95.0 x 66.0 x 9.00

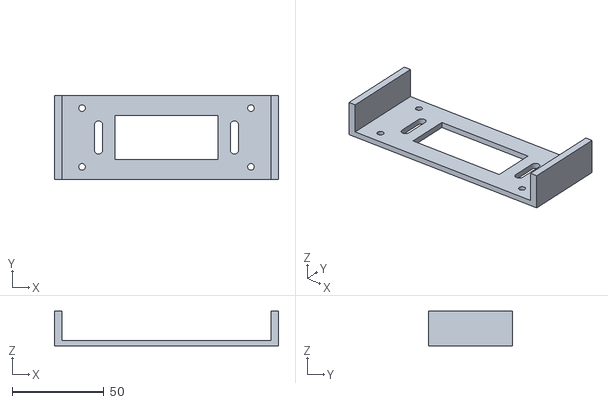
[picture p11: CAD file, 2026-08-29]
cad/chassis/stl/07_lipo_cradle.stl
122.0 x 46.0 x 19.0

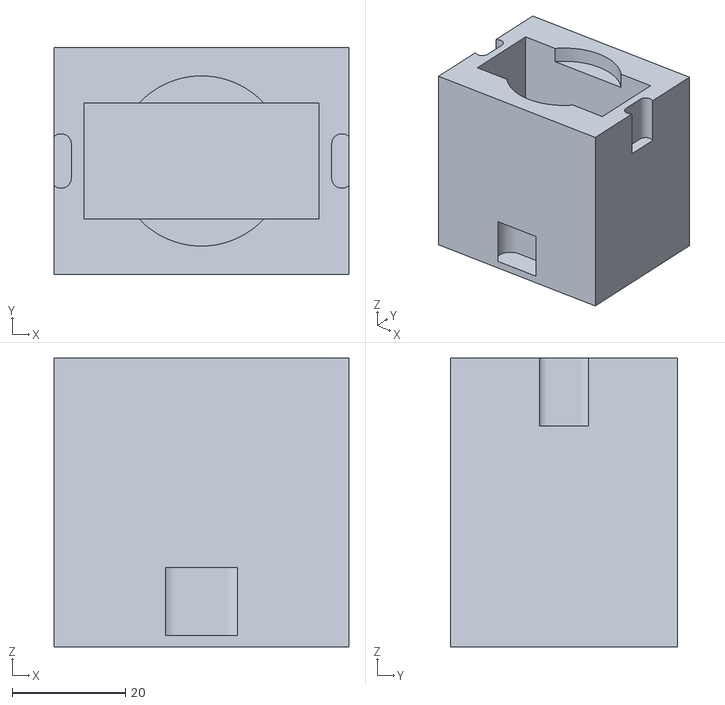
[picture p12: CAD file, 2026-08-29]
cad/chassis/stl/08_turret_base.stl
52.0 x 40.0 x 50.9

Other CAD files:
cad/chassis/stl/01_deck.stl

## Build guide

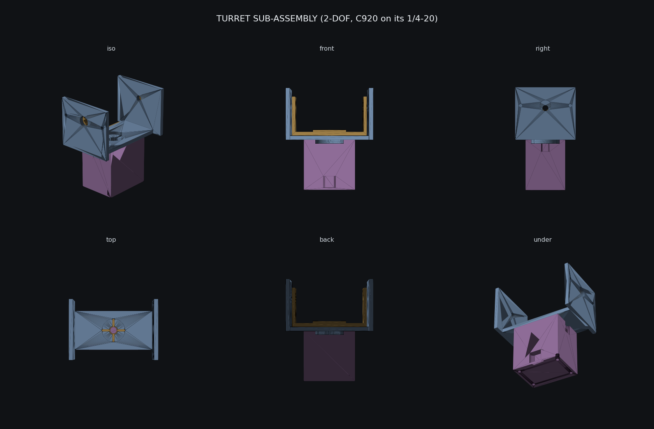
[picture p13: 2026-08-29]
cad/chassis/render/11_turret_assembly.png

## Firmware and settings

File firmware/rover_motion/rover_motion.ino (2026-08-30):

// rover_motion.ino v3 — Field Triage Rover: wheels + servos on one Mega
//
// Target: Arduino Mega 2560. Wheels through TWO L298N modules (all 12 pins
// independent, LastMinuteEngineers-style); servos through a PCA9685 on the
// Mega's I2C (SDA 20, SCL 21) — the PCA9685 makes its own pulses, so the old
// Servo-library/Timer1 conflict does not exist here.
//
// Servo roster (as physically plugged, re-confirmed 2026-08-29 late night):
//   ch0 tilt  = MG996R (healthy — held center in the hand test)
//   ch1 probe = MG90S  — BUILDER'S CHOICE against the force calc: ~12 N at
//               stall vs 8.8 N loose-mix load (22 N in garden soil). Works
//               only in very loose potting mix; if it hums without moving,
//               send PROBE 0 immediately. MG996R remains the correct part.
//               Fenced to 900-2400 us (30-150 deg): "retracted" = 30 deg, so
//               it never reaches its end-stop. 120 deg sweep = ~25.7 mm
//               insertion (HANDOFF graceful-degradation case), not 35 mm.
//   ch2 pan   = spins continuously on any pulse (continuous-rotation or
//               broken) -> DISABLED, gets no pulses. See PAN_ENABLED.
//
// Serial protocol (ASCII, newline-terminated), 115200 baud:
//   PING                  -> OK PONG
//   FWD <ms> <pwm>        -> OK FWD      auto-stops after <ms>
//   REV <ms> <pwm>        -> OK REV
//   SPIN <ms> <pwm> <L|R> -> OK SPIN
//   STOP                  -> OK STOP
//   PROBE <0-100>         -> OK PROBE    0 = retracted, 100 = inserted
//   PAN <deg> / TILT <deg>-> OK PAN|TILT   (PAN: ERR pan_disabled — see below)
//   PANSPIN <ms> <L|R>    -> OK PANSPIN  timed nudge of the continuous pan
//                            servo (max 2000 ms), then power cut — it coasts
//   HOME                  -> OK HOME
//   STATUS -> OK <drive> <pwm> <probe> <pan> <tilt> <settled> <uptime>
//
// Safety: no untimed motion; 400 ms host watchdog; PROBE refused while
// driving; driving refused while the probe is deployed; ~83 deg/s servo slew.
// Rules: IN pins only digitalWrite, EN pins only analogWrite, stop = EN 0.

#include <Wire.h>
#include <Adafruit_PWMServoDriver.h>

// ---- wheels: two L298N modules ---------------------------------------------
//                       EN  IN-a IN-b
const uint8_t FL[3] = {  9,  8,   7 };   // front-left   board1 ENA/IN1/IN2
const uint8_t RL[3] = {  3,  5,   4 };   // rear-left    board1 ENB/IN3/IN4
const uint8_t FR[3] = { 10, 11,  12 };   // front-right  board2 ENA/IN1/IN2
const uint8_t RR[3] = {  6, 13,   2 };   // rear-right   board2 ENB/IN3/IN4
const uint8_t* MOTOR[4] = { FL, RL, FR, RR };

// Flip per motor if it runs backward — never touch the EN pins.
// Bench-measured 2026-08-30: both REAR motors are wired mirror-image
// to the fronts (FWD ran fronts fwd + rears back), so RL and RR flip.
const bool FWD_HIGH[4] = { true, false, true, false };   // FL RL FR RR

// 3-6 V TT motors on a ~9 V rail (3S minus the L298 drop).
const uint8_t MAX_PWM = 160;
const unsigned long WATCHDOG_MS = 400;
const unsigned long MAX_DRIVE_MS = 10000;

// ---- servos: PCA9685 --------------------------------------------------------
Adafruit_PWMServoDriver pca;
const uint8_t CH_TILT = 3, CH_PROBE = 1, CH_PAN = 2;  // tilt moved to ch3 (builder rewire); ch0 now empty, ch2 = retired fried servo slot
const int US_MIN = 600, US_MAX = 2400;
const int US_PROBE_MIN = 600;                // ABSOLUTE floor — servo pulse limit. Any more depth = re-mesh the pinion lower. LISTEN for buzz at full DOWN.
const int US_PROBE_MAX = 2150;               // UP limit lowered 2026-08-30 ("goes too up") — park sits ~25 deg lower now
// Bench-measured 2026-08-30: the rack runs MIRRORED to the design assumption,
// so the pct->pulse map is inverted: PROBE 0 (retracted/up) = 2400 us,
// PROBE 100 (inserted/down) = 900 us. The fence bounds are unchanged.
// Tilt mechanism hammers its stop below ~74 deg (measured by successive
// approximation 2026-08-30); 118 deg is the highest angle proven clean.
const int US_TILT_MIN = 1340, US_TILT_MAX = 1780;   // 74..118 deg
// Per-channel slew: pan/tilt ~83 deg/s; the probe ~50 deg/s — gentle on the
// rack and pinion but not sluggish (builder-tuned 2026-08-29).
const float SLEW_US_PER_S[4] = { 1000.0, 900.0, 1000.0, 1000.0 };  // per channel; ch1 probe ~75 deg/s
const uint8_t SERVO_TICK_MS = 20;
const int HOME_US[4] = { 1500, US_PROBE_MAX, 1500, 1500 };  // ch0 unused, probe, pan(retired), tilt 90

float curUs[4], targetUs[4];
bool tiltEnergized = false;   // tilt stays pulseless until first commanded —
                              // no self-movement at plug-in (loose-horn drift guard)

// ---- state ------------------------------------------------------------------
enum DriveState { IDLE, FWD, REV, SPINL, SPINR, ARCL, ARCR, RARCL, RARCR };
DriveState drive = IDLE;
uint8_t drivePwm = 0;
unsigned long driveStopAt = 0, lastRxMs = 0, lastServoTick = 0;

char lineBuf[48];
uint8_t lineLen = 0;
bool lineOverflow = false;

// ---- motors -----------------------------------------------------------------
void stopMotors() {
  for (uint8_t m = 0; m < 4; m++) analogWrite(MOTOR[m][0], 0);
  drive = IDLE;
  drivePwm = 0;
}

void setMotor(uint8_t m, bool fwd, uint8_t pwm) {
  bool h = (fwd == FWD_HIGH[m]);
  digitalWrite(MOTOR[m][1], h ? HIGH : LOW);
  digitalWrite(MOTOR[m][2], h ? LOW : HIGH);
  analogWrite(MOTOR[m][0], pwm);
}

void startDrive(DriveState d, unsigned long ms, uint8_t pwm) {
  if (pwm > MAX_PWM) pwm = MAX_PWM;
  bool fwd = (d == FWD || d == ARCL || d == ARCR);
  bool rev = (d == REV || d == RARCL || d == RARCR);
  bool leftFwd  = fwd || d == SPINR;
  bool rightFwd = fwd || d == SPINL;
  // Arcs: the inner side runs at 40% — a smooth car-like veer.
  uint8_t leftPwm = pwm, rightPwm = pwm;
  if (d == ARCL || d == RARCL) leftPwm  = (uint8_t)(pwm * 0.4);
  if (d == ARCR || d == RARCR) rightPwm = (uint8_t)(pwm * 0.4);
  setMotor(0, leftFwd, leftPwm);
  setMotor(1, leftFwd, leftPwm);
  setMotor(2, rightFwd, rightPwm);
  setMotor(3, rightFwd, rightPwm);
  drive = d;
  drivePwm = pwm;
  driveStopAt = millis() + ms;
}

// ---- servos -----------------------------------------------------------------
// The pan servo turned out to be continuous-rotation/broken: it spins on any
// pulse, including center. Until a real positional servo replaces it, ch0
// gets NO pulses at all (a pulseless servo goes limp and stays still).
const bool PAN_ENABLED = false;

// Timed-nudge pan for the continuous servo: pulse off-center for a bounded
// time, then cut pulses entirely so it stops. No absolute angle exists.
const int PANSPIN_US_L = 1250, PANSPIN_US_R = 1750;  // strong enough to clear the dead zone
unsigned long panSpinUntil = 0;
bool panSpinning = false;

// The MG90S (probe, ch1) binds at its end-stops: hard-fence it at the
// pulse-write level. No command gets past this.
void writeServoUs(uint8_t ch, float us) {
  if (ch == CH_PAN && !PAN_ENABLED) {
    pca.setPWM(ch, 0, 0);   // zero pulse width = servo limp, no spinning
    return;
  }
  if (ch == CH_PROBE) {
    if (us < US_PROBE_MIN) us = US_PROBE_MIN;
    if (us > US_PROBE_MAX) us = US_PROBE_MAX;
  }
  if (ch == CH_TILT) {
    if (us < US_TILT_MIN) us = US_TILT_MIN;
    if (us > US_TILT_MAX) us = US_TILT_MAX;
  }
  pca.setPWM(ch, 0, (int)(us * 4096.0 / 20000.0 + 0.5));  // 50 Hz frame
}

bool servosSettled() {
  for (uint8_t i = 0; i < 4; i++) {
    if (i == 0 || i == CH_PAN) continue;   // unused / retired channels
    if (fabs(curUs[i] - targetUs[i]) > 6.0) return false;
  }
  return true;
}

bool probeRetracted() {
  return targetUs[CH_PROBE] >= US_PROBE_MAX - 6 && curUs[CH_PROBE] >= US_PROBE_MAX - 24;
}

void servoTick() {
  unsigned long now = millis();
  if (now - lastServoTick < SERVO_TICK_MS) return;
  float dt = (now - lastServoTick) / 1000.0;
  lastServoTick = now;
  for (uint8_t i = 0; i < 4; i++) {
    if (i == 0 || (i == CH_PAN && !PAN_ENABLED)) continue;  // empty / retired
    if (i == CH_TILT && !tiltEnergized) continue;
    float step = SLEW_US_PER_S[i] * dt;
    float d = targetUs[i] - curUs[i];
    if (fabs(d) <= step) curUs[i] = targetUs[i];
    else curUs[i] += (d > 0 ? step : -step);
    writeServoUs(i, curUs[i]);
  }
}

int probePct() { return (int)((US_PROBE_MAX - curUs[CH_PROBE]) * 100.0 / (US_PROBE_MAX - US_PROBE_MIN) + 0.5); }
int panDeg()   { return (int)((curUs[CH_PAN] - US_MIN) / 10.0 + 0.5); }
int tiltDeg()  { return (int)((curUs[CH_TILT] - US_MIN) / 10.0 + 0.5); }

// ---- protocol ---------------------------------------------------------------
void err(const char* reason) {
  Serial.print(F("ERR "));
  Serial.println(reason);
}

bool parseLong(const char* s, long* out, long lo, long hi) {
  if (s == NULL || *s == '\0') return false;
  char* end;
  long v = strtol(s, &end, 10);
  if (*end != '\0' || v < lo || v > hi) return false;
  *out = v;
  return true;
}

void handleDriveCmd(DriveState d, const char* okName) {
  char* msTok = strtok(NULL, " ");
  char* pwmTok = strtok(NULL, " ");
  long ms, pwm;
  if (!parseLong(msTok, &ms, 1, MAX_DRIVE_MS) || !parseLong(pwmTok, &pwm, 0, 255)) {
    err("bad_args");
    return;
  }
  if (d == SPINL || d == ARCL || d == RARCL) {
    char* side = strtok(NULL, " ");
    if (side == NULL || side[1] != '\0' || (side[0] != 'L' && side[0] != 'R')) {
      err("bad_args");
      return;
    }
    if (side[0] == 'R') d = (d == SPINL) ? SPINR : (d == ARCL) ? ARCR : RARCR;
  }
  if (!probeRetracted()) {  // rolling with the probe down snaps the probe
    err("probe_deployed");
    return;
  }
  startDrive(d, (unsigned long)ms, (uint8_t)pwm);
  Serial.print(F("OK "));
  Serial.println(okName);
}

void handleLine(char* line) {
  char* cmd = strtok(line, " ");
  if (cmd == NULL) return;

  if (strcmp(cmd, "PING") == 0) {
    Serial.println(F("OK PONG"));

  } else if (strcmp(cmd, "FWD") == 0) {
    handleDriveCmd(FWD, "FWD");
  } else if (strcmp(cmd, "REV") == 0) {
    handleDriveCmd(REV, "REV");
  } else if (strcmp(cmd, "SPIN") == 0) {
    handleDriveCmd(SPINL, "SPIN");
  } else if (strcmp(cmd, "ARC") == 0) {
    handleDriveCmd(ARCL, "ARC");
  } else if (strcmp(cmd, "RARC") == 0) {
    handleDriveCmd(RARCL, "RARC");

  } else if (strcmp(cmd, "STOP") == 0) {
    stopMotors();
    Serial.println(F("OK STOP"));

  } else if (strcmp(cmd, "PROBE") == 0) {
    long pct;
    if (!parseLong(strtok(NULL, " "), &pct, 0, 100)) { err("bad_args"); return; }
    if (drive != IDLE) { err("moving"); return; }
    targetUs[CH_PROBE] = US_PROBE_MAX - pct * (US_PROBE_MAX - US_PROBE_MIN) / 100.0;
    Serial.println(F("OK PROBE"));

  } else if (strcmp(cmd, "PAN") == 0 || strcmp(cmd, "TILT") == 0) {
    long deg;
    if (!parseLong(strtok(NULL, " "), &deg, 0, 180)) { err("bad_args"); return; }
    if (cmd[0] == 'P' && !PAN_ENABLED) { err("pan_disabled"); return; }
    if (cmd[0] == 'T') tiltEnergized = true;
    targetUs[cmd[0] == 'P' ? CH_PAN : CH_TILT] = US_MIN + deg * 10.0;
    Serial.println(cmd[0] == 'P' ? F("OK PAN") : F("OK TILT"));

  } else if (strcmp(cmd, "PANSPIN") == 0) {
    char* msTok = strtok(NULL, " ");
    char* sideTok = strtok(NULL, " ");
    long ms;
    if (!parseLong(msTok, &ms, 1, 2000) || sideTok == NULL || sideTok[1] != '\0'
        || (sideTok[0] != 'L' && sideTok[0] != 'R')) { err("bad_args"); return; }
    int us = (sideTok[0] == 'L') ? PANSPIN_US_L : PANSPIN_US_R;
    pca.setPWM(CH_PAN, 0, (int)(us * 4096.0 / 20000.0 + 0.5));
    panSpinUntil = millis() + ms;
    panSpinning = true;
    Serial.println(F("OK PANSPIN"));

  } else if (strcmp(cmd, "HOME") == 0) {
    if (drive != IDLE) { err("moving"); return; }
    tiltEnergized = true;
    for (uint8_t i = 0; i < 3; i++) targetUs[i] = HOME_US[i];
    Serial.println(F("OK HOME"));

  } else if (strcmp(cmd, "STATUS") == 0) {
    static const char* names[] = { "IDLE", "FWD", "REV", "SPINL", "SPINR", "ARCL", "ARCR", "RARCL", "RARCR" };
    Serial.print(F("OK "));
    Serial.print(names[drive]); Serial.print(' ');
    Serial.print(drivePwm);     Serial.print(' ');
    Serial.print(probePct());   Serial.print(' ');
    Serial.print(panDeg());     Serial.print(' ');
    Serial.print(tiltDeg());    Serial.print(' ');
    Serial.print(servosSettled() ? 1 : 0); Serial.print(' ');
    Serial.println(millis());

  } else {
    err("unknown_cmd");
  }
}

// ---- setup / loop -----------------------------------------------------------
void setup() {
  for (uint8_t m = 0; m < 4; m++)
    for (uint8_t k = 0; k < 3; k++) pinMode(MOTOR[m][k], OUTPUT);
  stopMotors();

  pca.begin();
  pca.setPWMFreq(50);
  for (uint8_t i = 0; i < 4; i++) {
    curUs[i] = (i == CH_PROBE) ? 1500 : HOME_US[i];  // probe eases from mid to park
    targetUs[i] = HOME_US[i];
    if (i == 0 || i == CH_PAN || i == CH_TILT) { pca.setPWM(i, 0, 0); continue; }  // silent
    writeServoUs(i, curUs[i]);
  }

  Serial.begin(115200);
  lastRxMs = millis();
  lastServoTick = millis();
  Serial.println(F("READY rover_motion 3.0"));
}

void loop() {
  unsigned long now = millis();
  while (Serial.available() > 0) {
    char c = (char)Serial.read();
    lastRxMs = now;
    if (c == '\n' || c == '\r') {
      if (lineOverflow) { err("line_too_long"); lineOverflow = false; lineLen = 0; }
      else if (lineLen > 0) { lineBuf[lineLen] = '\0'; handleLine(lineBuf); lineLen = 0; }
    } else if (lineLen < sizeof(lineBuf) - 1) {
      lineBuf[lineLen++] = c;
    } else {
      lineOverflow = true;
    }
  }
  if (drive != IDLE) {
    if ((long)(now - driveStopAt) >= 0) stopMotors();
    else if (now - lastRxMs > WATCHDOG_MS) stopMotors();
  }
  if (panSpinning && (long)(now - panSpinUntil) >= 0) {
    pca.setPWM(CH_PAN, 0, 0);   // cut pulses — continuous servo coasts to a stop
    panSpinning = false;
  }
  servoTick();
}

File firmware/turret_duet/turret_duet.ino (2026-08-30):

// turret_duet.ino — standalone kinematic pan/tilt show. NO USB needed once
// flashed: unplug and let it run. Wheels untouched.
//
// tilt (ch0, MG996R): asymmetric sine 74-118 deg (the mechanism has a
//   mechanical floor near ~62-70 deg discovered by hammering; stay above it)
// pan  (ch2, continuous): 300 ms alternating nudges, fired ONLY while the
//   tilt passes near center — big servos take turns, so the 6 V rail never
//   sees both peaks at once (the intermittent-hammer fix).
// probe (ch1): untouched, no pulses.

#include <Wire.h>
#include <Adafruit_PWMServoDriver.h>

Adafruit_PWMServoDriver pca;
const uint8_t CH_TILT = 0, CH_PROBE = 1, CH_PAN = 2;
const int PAN_L = 1250, PAN_R = 1750;

unsigned long t0, lastNudge = 0, panOffAt = 0;
bool panOn = false, nudgeRight = true;

void writeUs(uint8_t ch, float us) {
  pca.setPWM(ch, 0, (int)(us * 4096.0 / 20000.0 + 0.5));
}

void setup() {
  pca.begin();
  pca.setPWMFreq(50);
  pca.setPWM(CH_PROBE, 0, 0);          // probe limp
  pca.setPWM(CH_PAN, 0, 0);            // pan off until first nudge
  writeUs(CH_TILT, 1500);              // tilt level
  delay(1500);
  t0 = millis();
}

void loop() {
  unsigned long now = millis();
  float t = (now - t0) / 1000.0;

  float tilt = 96.0 + 22.0 * sin(2 * PI * t / 5.0);   // 74..118, floor-safe
  writeUs(CH_TILT, 600.0 + tilt * 10.0);

  if (!panOn && fabs(tilt - 96.0) < 8.0 && now - lastNudge > 2000) {
    writeUs(CH_PAN, nudgeRight ? PAN_R : PAN_L);
    nudgeRight = !nudgeRight;
    panOn = true;
    panOffAt = now + 300;
    lastNudge = now;
  }
  if (panOn && (long)(now - panOffAt) >= 0) {
    pca.setPWM(CH_PAN, 0, 0);          // cut pan pulses: coast to stop
    panOn = false;
  }
  delay(20);
}

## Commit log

2026-08-29 Scaffold repo: HANDOFF.md + surviving chassis CAD from ~/Developer/files
    Firmware and probe module listed in HANDOFF §6 were not recovered from
    disk; rebuilt/reported separately.
    [01_deck.step, 01_deck.stl, 02_motor_clamp.stl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]
2026-08-29 Rebuild rover_motion.ino from HANDOFF §4 spec (original lost)
    Compiles for arduino:avr:uno (7836B flash / 492B RAM). Implements the
    full serial protocol, timed-motion auto-stop, 400ms host watchdog,
    PROBE-refused-while-moving, ~83°/s servo slew, READY banner. Adds the
    reciprocal guard: drive commands refused while probe is deployed.
    Wheels paired on channels A/B per HANDOFF §3 resolution 1.
2026-08-29 Pi-side Rover serial driver + 11 tests (HANDOFF §8 task 1)
    READY-banner sync on connect, OK/ERR/timeout parsing, STATUS dataclass,
    wait_for_stop() as watchdog keepalive, client-side validation, fake-serial
    tests pass with no hardware.
2026-08-29 Fusion rule table + soil calibration with tests (HANDOFF §8 tasks 2-3)
    Total 3x3 triage table (moisture LOW/NORMAL/FAULT x leaf HEALTHY/
    ANOMALOUS/UNKNOWN) with abstention as a first-class outcome; the judge
    case (moisture 0.42, confidence 0.55) is a tested table lookup. Two-point
    soil calibration with plausibility bounds and a boot self-check so a
    broken probe reads as a fault, not a drought. 29 tests pass.
    [soil.py, triage.py]
2026-08-29 Leaf vision with abstention (task 4) + STATUS.md session record
    classify_leaf() calls Claude with a constrained JSON schema; every
    failure path abstains instead of guessing. 37 tests total pass.
    STATUS.md records what was lost, rebuilt, and still open.
    [leaf.py]
2026-08-29 Playable mock assembly: generator, GLB, and WebGL viewer template
    47 parts: the 9 surviving chassis STLs placed on the deck's own bolt
    patterns + clearly-colored mock placeholders (lost probe module, wheels,
    motors, boards, camera). Viewer published as an artifact; the wheel/deck
    corner clip at track 170 is shown, not hidden — real deck defect, see
    STATUS.md.
2026-08-29 Record deck feature-axis/track-170 defect found during mock assembly
2026-08-29 Add 4-channel DC motor bench test sketch (no Servo lib, all channels PWM)
2026-08-29 Record LiPo pack specs from vendor listing (30C, 106x18x20mm) — closes open question 5
2026-08-29 Architecture v2: dual L298N wheels + PCA9685 servos after shield death
    Shield L298P killed by reverse polarity (logic lives, channels dead).
    rover_motion.ino v2 is wheels-only on 2x L298N (channels jumped, one
    motor per channel); pi/actuators.py drives probe/pan/tilt via PCA9685
    with slew, sample() insert-dwell-retract, and the probe-vs-motion
    interlock moved Pi-side. Servo roster: MG996R probe+tilt, SG90 pan.
    Bench sketches + servo_test.py added. 44 tests pass; both sketches
    compile.
    [motor_test_l298n.ino, rover.py, rover_motion.ino]
2026-08-29 Re-pin to 12-wire independent L298N wiring (builder's choice)
    Board1/LEFT on the LastMinuteEngineers diagram pins (9,8,7,5,4,3),
    Board2/RIGHT on 10,12,13,A0,A1,11. rover_motion v2.1 drives four motors
    individually with per-motor FWD_HIGH flips; test sketch now exercises
    each motor separately (1/2/3/4/l/r/g/s). Both compile.
    [motor_test_l298n.ino, rover_motion.ino]
2026-08-29 Move to Arduino Mega; board-2 pins 10/11/12/13/2/6; add LME-style 4-motor demo
    Board 1 keeps the verified-working LME pins. All three sketches compile
    for both arduino:avr:mega and arduino:avr:uno.
2026-08-30 Firmware v3: one Mega runs wheels + PCA9685 servos; full protocol restored
    PCA9685 moves from the Pi to the Mega's I2C — no Servo-library timer
    issue exists with external PWM, and both safety interlocks return to
    firmware. Servo roster: MG996R probe, MG90S pan, MG996R tilt. rover.py
    regains probe/pan/tilt/home plus sample() insert-dwell-retract; the
    Pi-side actuators layer is retired. 40 tests pass; compiles for Mega.
    [rover.py, rover_motion.ino]
2026-08-30 Remap servo channels as plugged: ch0 tilt, ch1 probe (MG90S), ch2 pan
    Builder's override on the probe servo, margin warning documented in
    firmware header and STATUS.md. Compiles for Mega.
2026-08-30 Add showcase demo: eased turret sweeps, steady probe cycle, wheel routine
2026-08-30 Add calm one-axis-at-a-time servo demo (wire-tangle-friendly)
2026-08-30 Add continuous sweep demo (mg90 ±30, pan/tilt ±45) and servo center test
2026-08-30 Fence the MG90S in rover_motion too: pan pulses clamped 900-2100us
2026-08-30 Final servo channel map: ch0 pan 996, ch1 probe MG90S (fenced 900-2400us), ch2 tilt 996
    Probe retract now parks at 30 deg so the MG90S never reaches an end-stop;
    120 deg sweep = ~25.7 mm insertion per the HANDOFF degradation case.
2026-08-30 Add probe limit finder: crawl ch1, reverse+note angle on keypress
    [probe_limit_finder.ino]
2026-08-30 Slow probe slew to ~35 deg/s (per-channel slew rates)
2026-08-30 Probe slew up to ~50 deg/s per bench feel
2026-08-30 Disable pan channel: servo is continuous-rotation/broken, spins on any pulse
    ch0 receives zero pulse width (limp) until a positional servo replaces it;
    PAN returns ERR pan_disabled.
    [rover_motion.ino]
2026-08-30 Add pan-only center-hold test (probe/tilt limp)
2026-08-30 Correct channel map (re-confirmed): ch0 tilt, ch1 probe, ch2 pan disabled
    The pan-disable now lands on ch2, the actually-spinning servo; tilt on
    ch0 re-enabled.
    [rover_motion.ino]
2026-08-30 Update STATUS: corrected channel map, pan disabled, probe limits uncalibrated
2026-08-30 PANSPIN <ms> <L|R>: timed nudges for the continuous pan servo
    Bounded 2s pulse then zero pulses (coast). servoTick skips the pan
    channel so it can't clobber the nudge. PAN stays disabled.
    [rover_motion.ino]
2026-08-30 Stronger PANSPIN pulses (1250/1750us) to clear servo dead zone
2026-08-30 Milestone: full bench bring-up — all actuators verified under serial command
2026-08-30 Raise turret duet tilt floor to 74 deg — mechanism hammers below ~70
2026-08-30 Per-plant vision pipeline: camera capture, pest/disease cause, fenced scan routine
    leaf.py gains a cause field (disease|pest) in the constrained schema;
    camera.py wraps C920 capture with warmup; station.py scans 4 poses inside
    the measured tilt fence with pan nudges only at center tilt, combines
    frames by majority-with-abstention, and fuses into a triage flag.
    rover.py gains pan_nudge(). 45 tests pass.
2026-08-30 Live plant-board dashboard served by the Pi (stdlib-only) + report persistence
    PlantReport.append_to() writes work/reports.jsonl; dashboard.py renders
    the color-coded heatmap board with auto-refresh, runs as a systemd user
    service on the Pi (survives reboot, restarts on crash). Verified from
    the Mac's browser across the campus network.
    [dashboard.py, station.py]
2026-08-30 Rover.connect falls back to PING when the MCU does not reset on port-open
    [rover.py]
2026-08-30 Fix connect contract test: dead board times out, quiet-but-alive board connects via PING
2026-08-30 Rover Remote: browser/phone control GUI with live camera feed
    Hold-to-drive pad (streamed 600ms bursts — release or WiFi loss stops
    within one burst via firmware auto-stop), tilt steps within the fence,
    pan nudges, probe presets, HOME, MJPEG stream, live status, reconnect.
    Tolerates missing Mega/camera gracefully. WASD/arrow keys supported.
    [drive_gui.py]
2026-08-30 GUI: STOP EVERYTHING bar + plain-language camera/probe controls
2026-08-30 Camera controls become hold-to-aim (4-deg glide steps, repeating nudges)
2026-08-30 Flip rear motor polarity: FWD_HIGH = {T,F,T,F} per bench observation
    Both rear motors were wired mirror-image; fronts and rears fought on
    every command, which also broke spins. Flashed via the Pi.
    [rover_motion.ino]
2026-08-30 Invert probe pct->pulse mapping: rack is mirrored to design assumption
    PROBE 0 (retracted) = 2400us, PROBE 100 (inserted) = 900us; interlock,
    pct readout, and HOME follow. Boot slews gently from the old park to the
    new one. Fence bounds unchanged.
    [rover_motion.ino]
2026-08-30 Arc driving (8-direction pad) + probe fence floor lowered to 750us
    ARC/RARC commands run the inner side at 40% for car-like veers; GUI pad
    gains diagonal hold buttons. Probe DOWN reaches ~25 deg deeper — builder
    to watch for end-stop buzz and report.
    [drive_gui.py, rover.py, rover_motion.ino]
2026-08-30 Probe floor to 640us; tilt stays pulseless until first command
    Tilt self-drift at plug-in guard: ch0 gets no pulses at boot, energizes
    on first TILT/HOME. Probe DOWN gains another ~11 deg; listen-test rule
    in comment; beyond this depth = re-mesh the pinion.
    [rover_motion.ino]
2026-08-30 Mac-side leaf turret tracker: stream in, green-region centroid, aim commands out
    All vision processing on the laptop; the rover only receives the same
    GUI aim commands. Verified: live frame read + detection over the network.
2026-08-30 Neural plant tracking: prebuilt YOLOv5n (COCO potted-plant) via OpenCV DNN
    ~127 ms/frame CPU inference on the Mac; green-region fallback when no
    potted plant is detected so a handheld leaf still tracks. Same turret
    control loop and safety fences.
2026-08-30 Retire fried pan servo: wheel spins become the pan axis
    The servo self-drives on bare power (dead control board) — physically
    unplugged. GUI head-turn buttons and the tracker's horizontal steering
    now use short SPIN bursts; tracker cooldown raised for settle time.
    [drive_gui.py, rover_motion.ino]
2026-08-30 Move tilt to PCA9685 ch3; ch0 empty, ch2 retired — all silent at boot
2026-08-31 Farm Board: dawn-gradient showpiece page at /farm
    Fixed sun + layered field silhouettes, glass stat cards for field /
    machine / judgment. Field numbers labeled demo; machine numbers real.
    [dashboard.py]
2026-08-31 One-button kinematic show for demo filming (abortable, watchdog-fed)
2026-08-31 README: full project story, honest ledger, provenance
2026-08-31 Farm Board: sensor section — moisture heatmap, day trend chart, farmer's card
2026-08-31 Repo made agent- and human-reviewable: llms.txt, ARCHITECTURE.md, mermaid README
    llms.txt per the 2026 agent-index convention (claims mapped to evidence
    files); ARCHITECTURE.md carries the deep content — protocol timing model,
    fence methodology, fusion semantics, servo-loop constants, inherited
    probe force analysis (labeled), power tree, failure root-cause ledger.
    README gains badges and rendered mermaid diagrams.
